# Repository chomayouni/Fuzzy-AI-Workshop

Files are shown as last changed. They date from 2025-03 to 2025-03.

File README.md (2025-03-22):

# Floating Ball Arduino Project: Using Fuzzy Logic

## Introduction

Welcome to the Floating Ball project! In this experiment, we'll use an Arduino to make a ball float in the air at a specific height. 

This project uses something called "fuzzy logic," which is a type of artificial intelligence that helps computers make decisions in a way that's more like how humans think. Instead of just "on" or "off," fuzzy logic can handle "kind of" or "almost" or "a little bit" - just like we do when we're thinking!

By the end of this project, you'll be able to control a floating ball using a joystick or let the Arduino control it automatically with fuzzy logic. 

 

## What You'll Need (Parts List)



- Arduino Uno or compatible board
- Ultrasonic distance sensor (HC-SR04)
- Small DC fan (5V or 12V) - We uses a 12V 80mm computer fan
- MOSFET transistor (for controlling the fan speed)
- Joystick module
- Ping pong ball (or other lightweight ball)
- Clear tube (where the ball will float)
- Breadboard and jumper wires
- USB cable for Arduino
- Power supply for the fan (depending on your fan's requirements)

## Library Installation

Before we start coding, we need to install some special libraries for our Arduino. Libraries are like extra tools that make it easier for us to use certain components.

### How to Install Libraries:

1. Open the Arduino IDE (the program we use to write code for Arduino)
2. Click on "Sketch" in the top menu
3. Select "Include Library" and then "Manage Libraries..."
4. In the search box, type each library name and click "Install" for each one:
   - "SimpleUltrasonic" - For measuring distance with the ultrasonic sensor
   - "Fuzzy" - For implementing fuzzy logic control

If you can't find these libraries, you can download them from these links:
- SimpleUltrasonic: https://github.com/arduino-libraries/SimpleUltrasonic
- Fuzzy: https://github.com/zerokol/eFLL (This is the eFLL - Embedded Fuzzy Logic Library)

## Hardware Assembly

Let's put everything together! Here's a step-by-step guide:



1. **Assemble the fan housing**: Grab the M3 Bolts, M3 nuts, the 80mm fan, and the 3D printed housings for the top and the bottom of the fans
   
   
   
   - Sandwch the fan between the 2 housings and insert the two M3 bolts as shown below:
     
     

   - Turn the module on its side and gently screw on the nuts. Be careful to nobreak the legs attached to the intake of the fan.
     
     

3. **Set up the tube**: Place your clear tube vertically in the 3D printed fan adapter - It should friction fit right in.
   
      

4.  **Assemble the Ultrasonic Sensor housing**:
   - Take the bracket and thread a ziptie thorugh
     
     

   - Attach the bracket to the top of the tub. It should be tight enough to stay, but loose enough to adjust
     
     

   - Insert the Ultrasonic sensor facing down into the tube. Secure it with electrical tape
     
     

6.  **Connect the ultrasonic sensor**:
   - Connect VCC pin to 5V on Arduino
   - Connect GND pin to GND on Arduino
   - Connect Trigger pin to Digital pin 2 on Arduino
   - Connect Echo pin to Digital pin 3 on Arduino

6. **Connect the joystick**:
   - Connect VCC to 5V on Arduino
   - Connect GND to GND on Arduino
   - Connect the X or Y output to Analog pin A0 on Arduino

7. **Connect the fan with MOSFET**:
   - Connect the fan's power wire to your power supply positive terminal
   - Connect the fan's ground wire to the MOSFET's drain pin
   - Connect the MOSFET's source pin to the power supply ground
   - Connect the MOSFET's gate pin to Digital pin 9 on Arduino
   - Add a 10K resistor between the MOSFET's gate and ground

8. **Final check**:
   - Make sure all ground connections are connected together
   - Double-check all connections before powering up
   - Place the fan at the bottom of the tube, pointing upward
  
   

## Understanding the Code

Our code does several important things:

1. **Reads the distance** to the ball using the ultrasonic sensor
2. **Smooths the readings** to prevent jittery measurements
3. **Calculates the ball's speed** to help make better decisions
4. **Uses fuzzy logic** to decide how fast the fan should blow
5. **Controls the fan speed** to keep the ball at the target position
6. **Reads the joystick** to let you change the target position

Let's break down some of the most important parts:

### Measuring Distance

The code uses the ultrasonic sensor to measure how far away the ball is. It sends out sound waves that bounce off the ball and come back. By measuring how long this takes, we can figure out the distance.

### Fuzzy Logic

This is the AI part! Fuzzy logic helps the Arduino decide how to control the fan based on:
- How far the ball is from the target position (the "error")
- How fast the ball is moving (going up, going down, or steady)

The code sets up rules like:

- If the ball is far below the target AND moving downward, turn the fan on high
- If the ball is at the target AND not moving much, keep the fan at medium
- If the ball is above the target AND moving upward, turn the fan to very low

### PWM Fan Control

PWM stands for "Pulse Width Modulation," and it's how we control the fan speed. Instead of just turning the fan on or off, PWM rapidly switches the power on and off. The more time it's on versus off, the faster the fan spins.

## How to Use the Project

1. **Upload the code** to your Arduino using the Arduino IDE
2. **Position everything**:
   - Fan at the bottom of the tube
   - Ball inside the tube
   - Ultrasonic sensor at the top of the tube, pointing down
3. **Power on** your Arduino and the fan power supply
4. **Watch the ball float**!
5. **Use the joystick** to change the target height of the ball

The default mode is "Fuzzy Mode" which means the Arduino's fuzzy logic is controlling the fan to keep the ball at the target height. You can move the joystick to change the target height.

# Introduction to Fuzzy Logic

Fuzzy logic is really cool because it works more like human thinking than regular computer logic. Here's a simple explanation:

## Regular (Boolean) Logic vs. Fuzzy Logic:

* **Regular Logic**: Things are either TRUE (1) or FALSE (0). A light is either ON or OFF.
* **Fuzzy Logic**: Things can be partially true. A light can be DIM, BRIGHT, or anything in between.

## Mamdani Fuzzy Logic Chart

Below is a visual representation of our fuzzy logic system:

*[See the detailed Mamdani Fuzzy Logic Chart below for a visual representation of our system]*

In our project, we use fuzzy logic to describe:

1. **How far from the target**:
   * VERY NEGATIVE (way below target)
   * NEGATIVE (a bit below target)
   * ZERO (at target)
   * POSITIVE (a bit above target)
   * VERY POSITIVE (way above target)

2. **Ball speed**:
   * GOING DOWN (moving downward)
   * STEADY (not moving much)
   * GOING UP (moving upward)

3. **Fan speed**:
   * VERY LOW (75% power)
   * LOW (78% power)
   * MEDIUM (80% power)
   * HIGH (82% power)
   * VERY HIGH (85% power)

The fuzzy controller combines these to make decisions. For example, if the ball is NEGATIVE (below target) and GOING UP, the fuzzy logic might set the fan to LOW because the ball is already moving in the right direction.

## Understanding the Mamdani Fuzzy System

The fuzzy logic control system in this project uses a Mamdani-type inference system with a K-map based rule generation approach. Let's break down what this means:

### How the Fuzzy System Works:

1. **Input 1: Position Error** - This shows how far the ball is from where we want it to be
   * Negative Far: Ball is way below target (0-85 on scaled range)
   * Negative Close: Ball is a bit below target (65-125 on scaled range)
   * Zero: Ball is at the target (100-140 on scaled range)
   * Positive Close: Ball is a bit above target (130-175 on scaled range)
   * Positive Far: Ball is way above target (150-255 on scaled range)

2. **Input 2: Ball Speed** - This shows how fast the ball is moving
   * Negative Fast: Ball moving down quickly (0-90 on scaled range)
   * Negative Slow: Ball moving down slowly (50-120 on scaled range)
   * Zero: Ball isn't moving much (100-155 on scaled range)
   * Positive Slow: Ball moving up slowly (140-200 on scaled range)
   * Positive Fast: Ball moving up quickly (150-255 on scaled range)

3. **Output: Fan Speed Adjustment** - Unlike the previous version, this system outputs delta values (changes to fan speed)
   * Very Negative: Decrease fan speed significantly (-0.01)
   * Negative: Decrease fan speed slightly (-0.005)
   * Zero: Keep fan speed the same (0.0)
   * Positive: Increase fan speed slightly (0.005)
   * Very Positive: Increase fan speed significantly (0.01)



## Fuzzy Logic Rule Chart

Below is a visual representation of all the fuzzy logic rules used in our system, organized as a K-map (Karnaugh map). This advanced representation helps us see patterns in how the controller makes decisions:



## Tuning Your Project

If your ball isn't floating stably, you might need to tune some values in the code:

1. **Fan Power Levels**: Look for these lines in the code:
```cpp
veryLow = new FuzzySet(76.5, 76.5, 76.5, 76.5);
low = new FuzzySet(78.0, 78.0, 78.0, 78.0);
medium = new FuzzySet(79.5, 79.5, 79.5, 79.5);
high = new FuzzySet(81.0, 81.0, 81.0, 81.0);
veryHigh = new FuzzySet(83.0, 83.0, 83.0, 83.0);
```
   You can change these numbers to adjust the fan power levels. The values represent the percentage of full power.

2. **Target Position Range**: Look for these lines:
```cpp
const float minTargetPosition = 3.0;
const float maxTargetPosition = 12.0;
```
   These values set the minimum and maximum target heights (in inches). Adjust them based on the height of your tube.

3. **Speed Filter**: If the ball speed calculations seem too jumpy, you can adjust this line:
```cpp
const float speedFilterAlpha = 0.15;
```
   A lower value will make the speed changes smoother but less responsive.

## Troubleshooting

If you run into problems, here are some things to check:

1. **Ball won't float at all**: 
   - Make sure your fan is powerful enough for your ball
   - Check that the fan is receiving power
   - Verify that PWM pin 9 is correctly connected

2. **Ball is unstable (bouncing up and down)**:
   - Try adjusting the fuzzy logic values for a smoother response
   - Increase the smoothingFactor for distance readings
   - Check if there are any air currents in the room affecting the ball

3. **Readings are inconsistent**:
   - Make sure the ultrasonic sensor is positioned correctly
   - Check that the ball is within the detection range of the sensor
   - Try reducing outside noise that might affect the ultrasonic sensor

4. **Arduino not responding**:
   - Check USB connection
   - Verify that the correct port and board are selected in Arduino IDE
   - Make sure libraries are installed correctly

## Going Further

Once you get the basic project working, here are some cool ideas to try:

1. **Add an LED display** to show the current height and target height
2. **Add buttons** to switch between different preset heights
3. **Create a game** where you try to keep the ball within a certain zone
4. **Experiment with different fuzzy logic rules** to see how they affect performance
5. **Try different types of balls** to see how the system adapts

## How It Connects to Real-World AI

This project is a small example of how artificial intelligence can be used in the real world:

- **Self-driving cars** use fuzzy logic and other AI techniques to make decisions about speed, braking, and steering
- **Smart home thermostats** use similar techniques to maintain comfortable temperatures
- **Industrial machinery** often uses fuzzy logic controllers for precise positioning

Congratulations on building your own AI-controlled system! You've taken your first step into the exciting world of fuzzy logic and control systems.

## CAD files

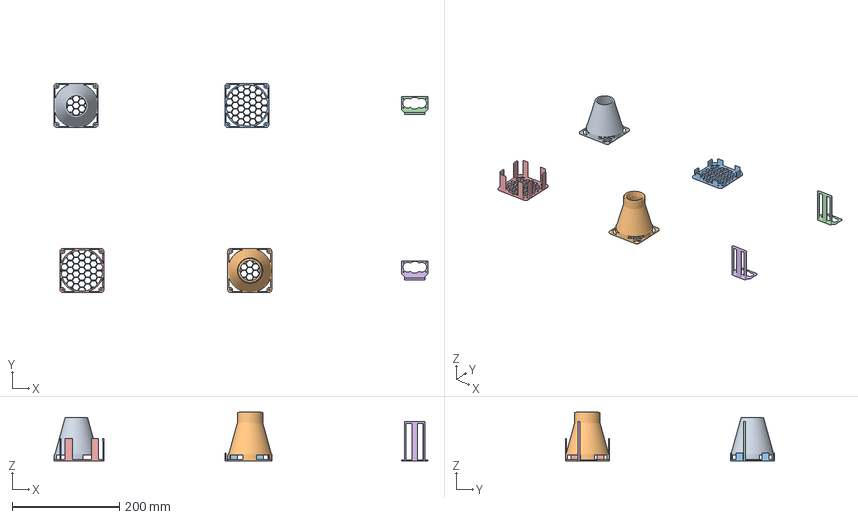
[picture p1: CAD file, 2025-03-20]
3D Models/Fuzzy_AI_Parts.3mf
696.3 x 389.3 x 90.9 mm
80 mm funnel v2
80 mm funnel v3
fan_guard
Frame (1) x 2
80mm_Offset v3

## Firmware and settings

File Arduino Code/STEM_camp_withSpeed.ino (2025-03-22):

#include <SimpleUltrasonic.h>
#include <Fuzzy.h>

#define PWM_D9_PIN 9  // Must be 9 or 10 (Timer1-based PWM)
#define JOYSTICK_PIN A0


#define PRINTS

// Ultrasonic Sensor (Trigger, Echo)
SimpleUltrasonic sensor(3, 2);

float currentFanPWM = 90.0; // Start with medium value

// Singleton Outputs:
// #define MAX_DELTA 0.015
// #define MIN_DELTA 0.01
//const float VERY_LOW_SPEED = (-MIN_DELTA);
//const float LOW_SPEED = (-MIN_DELTA/2);
//const float MID_SPEED =  0.0;
//const float HIGH_SPEED = (MAX_DELTA/2);
//const float VERY_HIGH_SPEED = (MAX_DELTA);

const float VERY_LOW_SPEED = -0.01;
const float LOW_SPEED = -0.005;
const float MID_SPEED = 0.0;
const float HIGH_SPEED = 0.005;
const float VERY_HIGH_SPEED = 0.01;

// Fuzzy Logic System
Fuzzy *fuzzy = new Fuzzy();
FuzzySet *neg_far, *neg_close, *zero_p, *pos_close, *pos_far;  // Target error
FuzzySet *neg_high, *neg_low, *zero_m, *pos_low, *pos_high;
FuzzySet *neg_fast, *neg_slow, *zero_s, *pos_slow, *pos_fast; // Speeds

// Toggle mode: 0 = Joystick (Manual), 1 = Fuzzy (Automatic)
bool fuzzyMode = true;

// Target position (in inches)
//const float targetDistance = 9.0;  // Set your desired target distance here

// Moving Average Filter for Smoothing Distance Measurements
float smoothedDistance = 0;
const int smoothingFactor = 10;  // Number of samples to average
float previousDistance = 0;
unsigned long previousTime, timea, timeb = 0;
float ballSpeed = 0;
float targetError = 0;  // Difference from target position
float currentTargetPosition = 12.0;  // Start at middle of range
const float minTargetPosition = 3.0;
const float maxTargetPosition = 28.0;

void updateTargetWithJoystick() {
    // Read joystick value
    int joystickValue = analogRead(JOYSTICK_PIN);
    
    // Calculate rate of change based on joystick position
    // Center position (around 512) = no change
    // Full right/up = fast increase, full left/down = fast decrease
    float rate = mapfloat(joystickValue, 0.0, 1023.0, -0.005, 0.005);
    
    // Create a dead zone in the middle to prevent drift
    if (abs(rate) < 0.002) {
        rate = 0.0;
    }
    
    // Update target position at constant rate
    currentTargetPosition += rate;
    
    // Constrain to valid range
    currentTargetPosition = constrain(currentTargetPosition, minTargetPosition, maxTargetPosition);
}


float mapfloat(float x, float in_min, float in_max, float out_min, float out_max) {
  // Check if input is out of range and constrain it
  if (x < in_min) x = in_min;
  if (x > in_max) x = in_max;
  
  // Perform the mapping calculation
  return (x - in_min) * (out_max - out_min) / (in_max - in_min) + out_min;
}

void updateSmoothedDistance(float newReading) {
    static float readings[smoothingFactor] = {0};
    static int index = 0;

    // Reject clearly erroneous readings
    if (newReading > 0 && newReading < 32) {  // Valid range check
        readings[index] = newReading;
        index = (index + 1) % smoothingFactor;

        // Use weighted moving average with emphasis on recent readings
        float sum = 0;
        float weightSum = 0;
        for (int i = 0; i < smoothingFactor; i++) {
            int j = (index - 1 - i + smoothingFactor) % smoothingFactor;
            float weight = smoothingFactor - i;
            if (readings[j] > 0) {  // Only include valid readings
                sum += readings[j] * weight;
                weightSum += weight;
            }
        }
        
        if (weightSum > 0) {
            smoothedDistance = sum / weightSum;
        }
    }
}

void updateBallSpeed() {
    unsigned long currentTime = millis();
    float deltaTime = (currentTime - previousTime) / 1000.0;
    
    if (deltaTime >= 0.05) {
        float instantSpeed = (previousDistance - smoothedDistance) / deltaTime;
        
        // Stronger filtering for better stability
        const float speedFilterAlpha = 0.15; // Lower value for more filtering
        ballSpeed = (speedFilterAlpha * instantSpeed) + ((1.0 - speedFilterAlpha) * ballSpeed);
        
        // Larger dead zone for near-zero speeds
        if (abs(ballSpeed) < 0.15) {
            ballSpeed = 0.0;
        }
        
        // Lower max speed values for more gentle transitions
        ballSpeed = constrain(ballSpeed, -8.0, 8.0);
        
        previousDistance = smoothedDistance;
        previousTime = currentTime;
    }
}


void setupFuzzy() {
    // Define input fuzzy variable for target error
    FuzzyInput *errorInput = new FuzzyInput(1);
    neg_far = new FuzzySet(0, 0, 40, 85);      // Far below target
    neg_close = new FuzzySet(65, 90, 110, 125);    // Below target
    zero_p = new FuzzySet(100, 115, 130, 140);        // At target
    pos_close = new FuzzySet(130, 140, 155, 175);        // Above target  
    pos_far = new FuzzySet(150, 170, 255, 255);          // Far above target
    errorInput->addFuzzySet(neg_far);
    errorInput->addFuzzySet(neg_close);
    errorInput->addFuzzySet(zero_p);
    errorInput->addFuzzySet(pos_close);
    errorInput->addFuzzySet(pos_far);
    fuzzy->addFuzzyInput(errorInput);

    FuzzyInput *speedInput = new FuzzyInput(2);
    neg_fast = new FuzzySet(0, 0, 20, 90);
    neg_slow = new FuzzySet(50, 70, 90, 120);   
    zero_s = new FuzzySet(100, 125, 135, 155);    
    pos_slow = new FuzzySet(140, 170, 180, 200);     
    pos_fast = new FuzzySet(150, 200, 255, 255);    
    speedInput->addFuzzySet(neg_fast);
    speedInput->addFuzzySet(neg_slow);
    speedInput->addFuzzySet(zero_s);
    speedInput->addFuzzySet(pos_slow);
    speedInput->addFuzzySet(pos_fast);
    fuzzy->addFuzzyInput(speedInput);

    FuzzyOutput *fanSpeed = new FuzzyOutput(1);
    neg_high = new FuzzySet(VERY_LOW_SPEED, VERY_LOW_SPEED, VERY_LOW_SPEED, VERY_LOW_SPEED);
    neg_low = new FuzzySet(LOW_SPEED, LOW_SPEED, LOW_SPEED, LOW_SPEED);      
    zero_m = new FuzzySet(MID_SPEED, MID_SPEED, MID_SPEED, MID_SPEED);   
    pos_low = new FuzzySet(HIGH_SPEED, HIGH_SPEED, HIGH_SPEED, HIGH_SPEED);     
    pos_high = new FuzzySet(VERY_HIGH_SPEED, VERY_HIGH_SPEED, VERY_HIGH_SPEED, VERY_HIGH_SPEED); 
    fanSpeed->addFuzzySet(neg_high);
    fanSpeed->addFuzzySet(neg_low);
    fanSpeed->addFuzzySet(zero_m);
    fanSpeed->addFuzzySet(pos_low);
    fanSpeed->addFuzzySet(pos_high);
    fuzzy->addFuzzyOutput(fanSpeed);

    // Generate fuzzy rules from K-map
    int ruleIndex = 1;
    FuzzySet *speedLevels[] = {pos_fast, pos_slow, zero_s, neg_slow, neg_fast};
    FuzzySet *posLevels[] = {neg_far, neg_close, zero_p, pos_close, pos_far};
    FuzzySet *outputLevels[5][5] = {
        {NULL, neg_low, neg_high, neg_high, NULL},
        {pos_low, zero_m, neg_low, neg_high, neg_high},
        {pos_high, pos_low, zero_m, neg_low, neg_high},
        {pos_high, pos_high, pos_low, zero_m, neg_low},
        {NULL, pos_high, pos_high, pos_low, NULL}
    };
   
    for (int i = 0; i < 5; i++) {
        for (int j = 0; j < 5; j++) {
          if (outputLevels[i][j] != NULL) 
          {
            FuzzyRuleAntecedent *antecedent = new FuzzyRuleAntecedent();
            antecedent->joinWithAND(speedLevels[i], posLevels[j]);
            FuzzyRuleConsequent *consequent = new FuzzyRuleConsequent();
            consequent->addOutput(outputLevels[i][j]);
            fuzzy->addFuzzyRule(new FuzzyRule(ruleIndex++, antecedent, consequent));
          }
        }
    }
}

void setupPWM() {
    pinMode(PWM_D9_PIN, OUTPUT);
    TCCR1A = _BV(COM1A1) | _BV(WGM11);
    TCCR1B = _BV(WGM13) | _BV(WGM12) | _BV(CS10);
    ICR1 = 320;  // 25kHz frequency
}

void setFanSpeed(float percentage) {
    OCR1A = (percentage / 100.0) * 320;  // Convert 0-100% to Timer1 PWM value
}

void setup() {
    Serial.begin(115200);
    sensor.begin();
    setupFuzzy();
    setupPWM();
    previousTime = millis();
}

void loop() {
    timea = millis();
    float distance = sensor.measureDistanceInInch();
    updateSmoothedDistance(distance);
    if (fuzzyMode) {
        updateBallSpeed();
        
        // Update target at constant rate based on joystick
        updateTargetWithJoystick();
        
        // Calculate error using the current target
        targetError = currentTargetPosition - smoothedDistance;
        targetError = constrain(targetError, -6.0, 6.0);
        float mappederror = mapfloat(targetError, -6.0, 6.0, 0.0, 255.0);
        ballSpeed = constrain(ballSpeed, -6.0, 6.0);
        float mappedspeed = mapfloat(ballSpeed, -6.0, 6.0, 0.0, 255.0);
        
        if (distance != -1) {
            #ifdef PRINTS
                Serial.print("Distance: ");
                Serial.print(smoothedDistance);
                Serial.print(" in\tTarget: ");
                Serial.print(currentTargetPosition);  // Print the current target
                Serial.print(" in\tError: ");
                Serial.print(targetError);
                Serial.print(" in\tSpeed: ");
                Serial.print(ballSpeed);
                Serial.print(" in/sec");
            #endif
            
            fuzzy->setInput(1, mappederror);
            fuzzy->setInput(2, mappedspeed);
            fuzzy->fuzzify();
            float fanPWM_delta = fuzzy->defuzzify(1);
            
            // // Adaptive rate limiting - faster during large errors
            // float maxChange = 0.2; // Normal rate limit
            // if (abs(targetError) > 3.0) {
            //     maxChange = 0.2; // Faster response for large errors
            // }
            
            // // Apply rate limiting
            // if (fanPWM_delta > lastfanPWM_delta + maxChange) {
            //     fanPWM_delta = lastfanPWM_delta + maxChange;
            // } else if (fanPWM_delta < lastfanPWM_delta - maxChange) {
            //     fanPWM_delta = lastfanPWM_delta - maxChange;
            // }
            
            currentFanPWM += fanPWM_delta;
            currentFanPWM = constrain(currentFanPWM, 0.0, 100.0);
            
            #ifdef PRINTS
                Serial.print("\tDelta speed: ");
                Serial.print(fanPWM_delta);
                Serial.print("\tFan speed: ");
                Serial.println(currentFanPWM);
            #endif

            // Apply fan power
            setFanSpeed(currentFanPWM);
        } else {
            Serial.println("Error: Measurement timeout");
        }
    } else {
        int joystickValue = analogRead(JOYSTICK_PIN);
        float pwmDutyCycle = mapfloat(joystickValue, 0.0, 1023.0, 50.0, 100.0);
        setFanSpeed(pwmDutyCycle);
        #ifdef PRINTS
            Serial.print("Manual Mode: \t Distance: ");
            Serial.print(smoothedDistance);
            Serial.print("\tFanspeed(%): ");
            Serial.println(pwmDutyCycle);
        #endif
    }
           // Debug output for input and output fuzzy sets
        // Serial.println("Error membership values:");
        // Serial.print("veryNegativeError: ");
        // Serial.println(veryNegativeError->getPertinence());
        // Serial.print("negativeError: ");
        // Serial.println(negativeError->getPertinence());
        // Serial.print("zeroError: ");
        // Serial.println(zeroError->getPertinence());
        // Serial.print("positiveError: ");
        // Serial.println(positiveError->getPertinence());
        // Serial.print("veryPositiveError: ");
        // Serial.println(veryPositiveError->getPertinence());
        
        // Serial.println("Speed membership values:");
        // Serial.print("goingDownFast: ");
        // Serial.println(goingDownFast->getPertinence());
        // Serial.print("goingDown: ");
        // Serial.println(goingDown->getPertinence());
        // Serial.print("steady: ");
        // Serial.println(steady->getPertinence());
        // Serial.print("goingUp: ");
        // Serial.println(goingUp->getPertinence());
        // Serial.print("goingUpFast: ");
        // Serial.println(goingUpFast->getPertinence());
         
        // Debug output for rule activations
        // Serial.println("Rule activations:");
        // bool anyRuleActive = false;
        // for (int i = 1; i <= 25; i++) {  // Now using 20 rules
        //     float activation = fuzzy->isFiredRule(i);
        //     // if (activation > 0) {
        //         anyRuleActive = true;
        //         Serial.print("Rule ");
        //         Serial.print(i);
        //         Serial.print(": ");
        //         Serial.print(activation);
        //         Serial.print(" ");
        //     // }
        // }
        // Serial.println(" ");
        
        // if (!anyRuleActive) {
        //     Serial.println("WARNING: No rules are active!");
        // }

    timeb = millis();
    delay(5);
}

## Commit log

2025-03-20 Add initial workspace configuration for Fuzzy-AI-Workshop-1
    [Fuzzy_AI_Parts.3mf]
2025-03-21 prints toggle
